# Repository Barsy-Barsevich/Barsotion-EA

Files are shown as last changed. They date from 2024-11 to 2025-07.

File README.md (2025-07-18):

# Barsotion GBK EpsilonAnomalain
Board computer for model rockets, the 10th board after Berkut

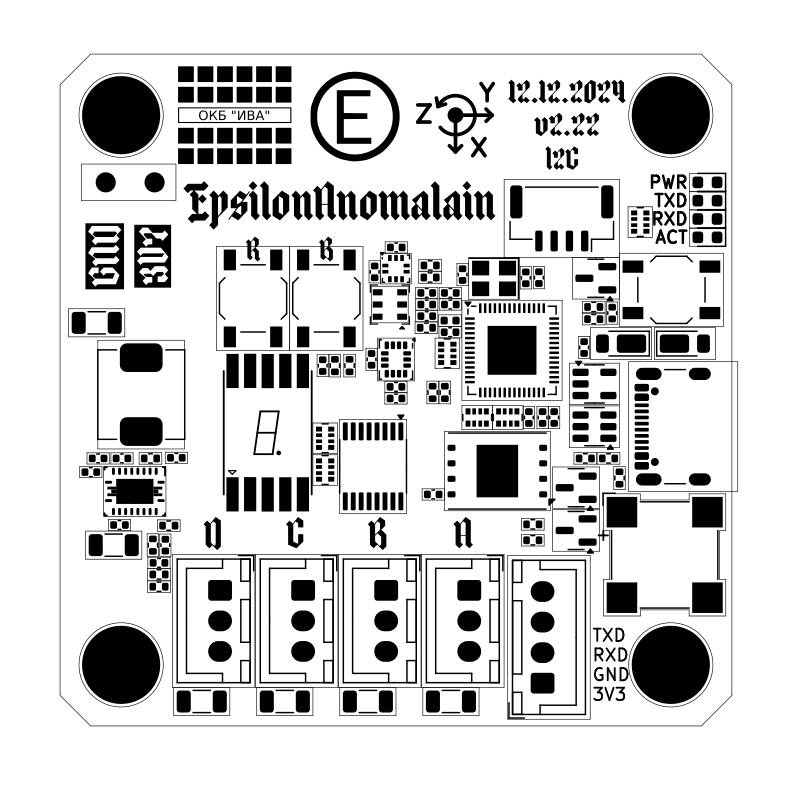
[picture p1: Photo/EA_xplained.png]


## ⚡️Manual
- [EA&TA_user_manual_revD.pdf (newest revision)](https://github.com/Barsy-Barsevich/Barsotion-TA/blob/main/Manual/EA%26TA_user_manual_revD.pdf)
- [EA&TA_user_manual_revC.pdf](https://github.com/Barsy-Barsevich/Barsotion-TA/blob/main/Manual/EA&TA_user_manual_revC.pdf)
- [EA&TA_user_manual_preliminary_edition_revB.pdf](https://github.com/Barsy-Barsevich/Barsotion-TA/blob/main/Manual/EA&TA_user_manual_preliminary_edition_revB.pdf)
- [EA&TA_user_manual_preliminary_edition_revA.pdf](https://github.com/Barsy-Barsevich/Barsotion-TA/blob/main/Manual/EA&TA_user_manual_preliminary_edition_revA.pdf)

## ⚡️Software
- [EA/TA software packet](https://github.com/Barsy-Barsevich/Barsotion-xA-software)

## ⚡️Continious progress
- [Previous version: Barsotion GBK DeltaAnomalain](https://github.com/Barsy-Barsevich/Barsotion-GBK-DeltaAnomalain)
- [Next version: Barsotion-TA (ThetaAnomalain)](https://github.com/Barsy-Barsevich/Barsotion-TA)

## ⚡️Schematic

## ⚡️Parameters
- Microcontroller: ESP32-S3FN8 (2x Xtensa LX7 core)
- Clock frequency: 240MHz
- Gyroscope: on-board ICM-42688-P (SPI, interrupt channel)
- Barometer: on-board, BMP388 (I2C)
- Hygrometer: on-board, AHT20 (I2C)
- Memory: 1Gbit SPI NAND Flash W25N04GVZEIG (Quad SPI)

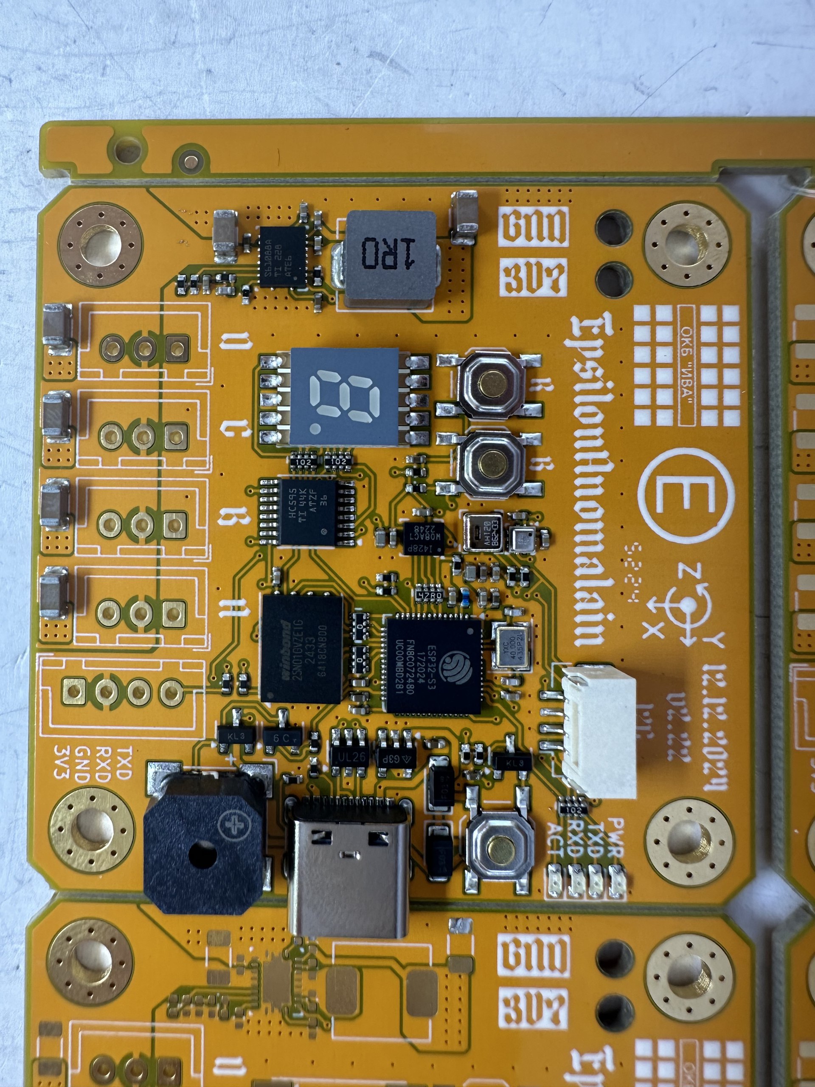
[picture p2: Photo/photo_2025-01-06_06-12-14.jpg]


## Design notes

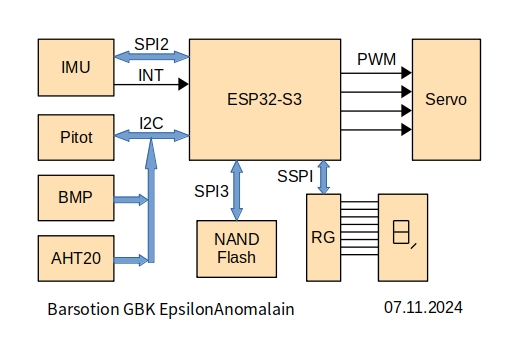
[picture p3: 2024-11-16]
Schematic/Barsotion_EA_BlockScheme1.jpg

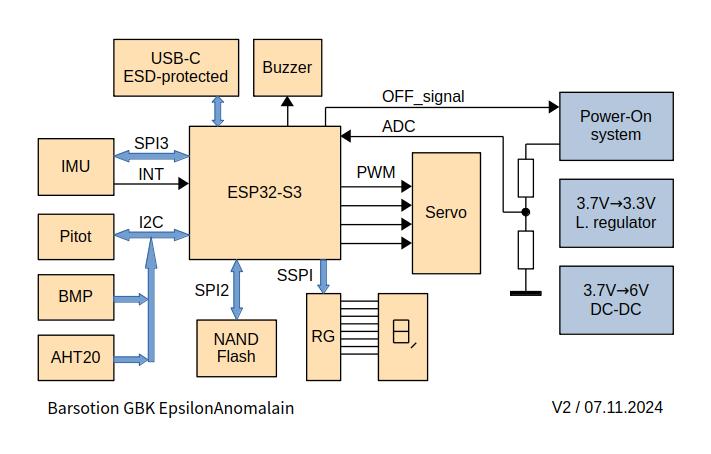
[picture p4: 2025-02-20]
Schematic/Barsotion_EA_BlockScheme2.jpg

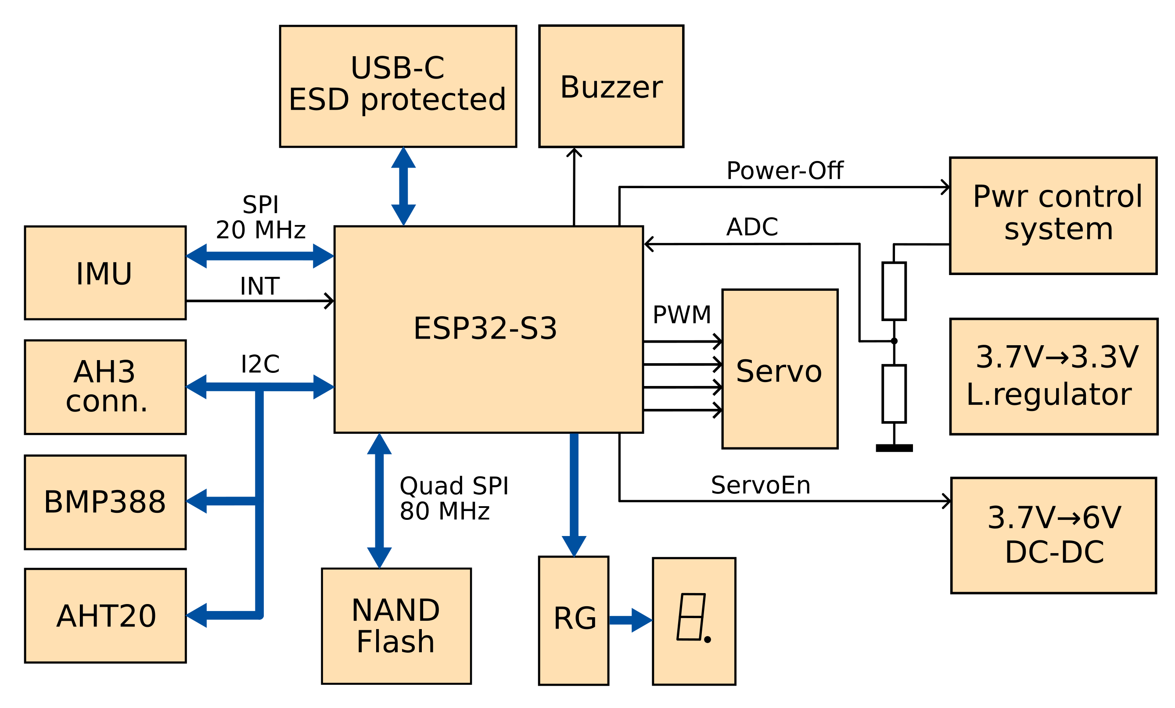
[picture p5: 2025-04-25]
Schematic/EA_Blockscheme.png

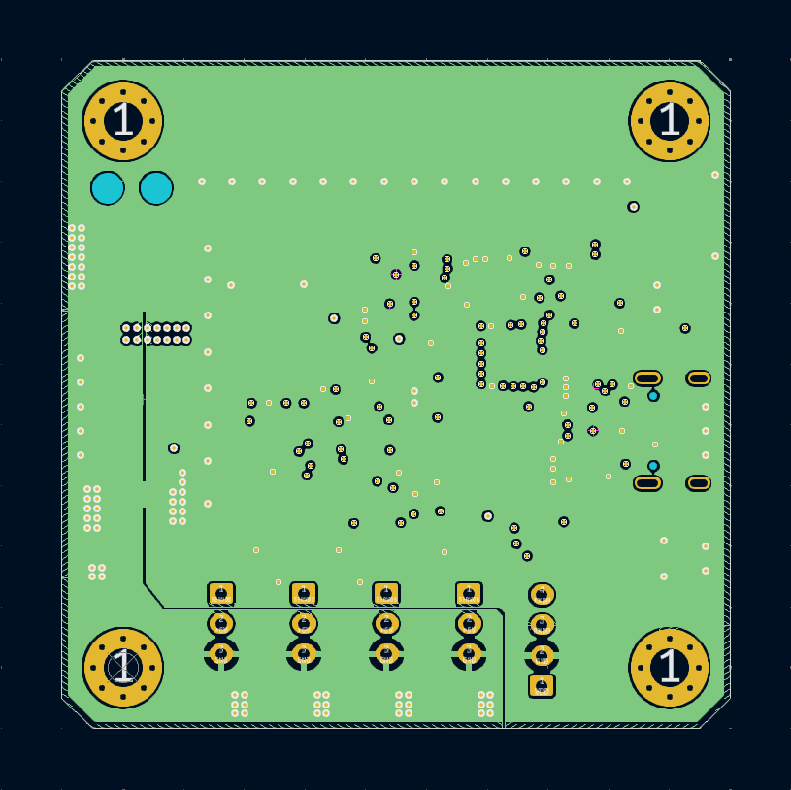
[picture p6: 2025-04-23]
Topology/EA Layer 2 - GND.png

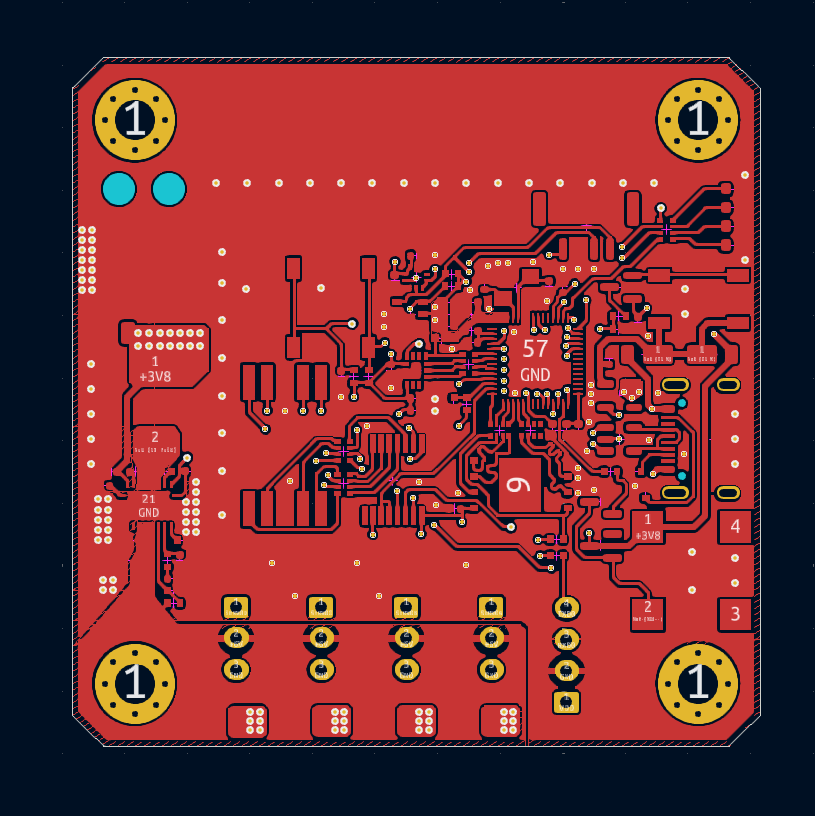
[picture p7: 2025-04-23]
Topology/EA Layer 1 - Top signal.png

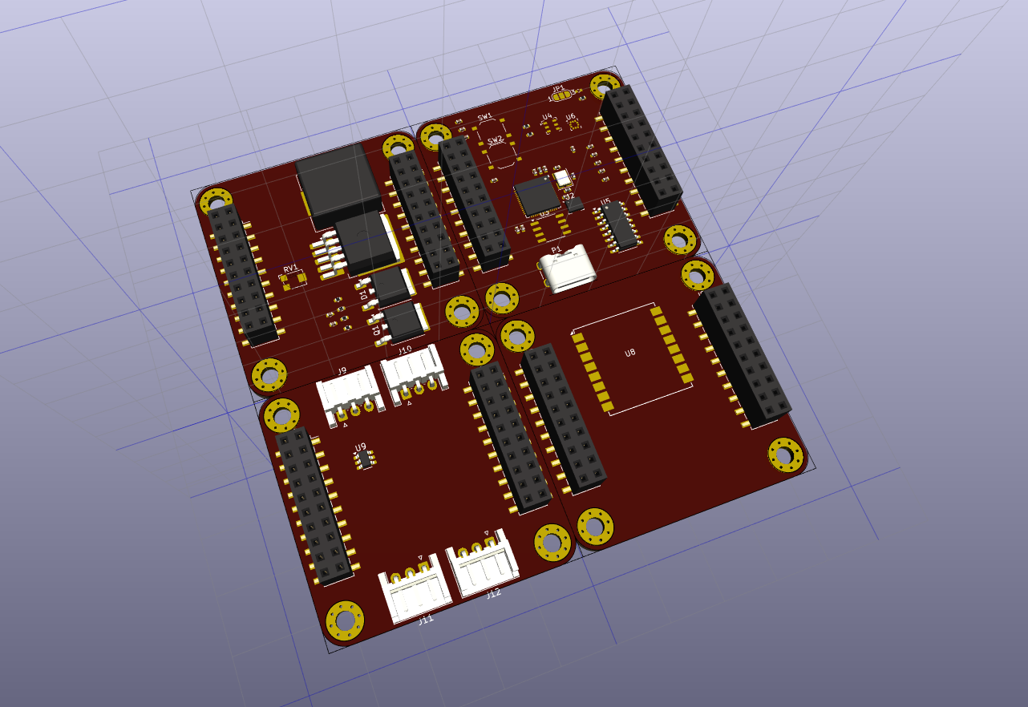
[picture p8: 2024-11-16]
Prev/EpsilonAnomalain/Screenshot at 2024-08-06 22-45-56.png

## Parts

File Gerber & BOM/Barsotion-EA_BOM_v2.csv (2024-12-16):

Reference | Value | Datasheet | Footprint | Qty | DNP | Description | Mfr.Part
BZ1 | CMT-8504-100 | https://www.lcsc.com/datasheet/lcsc_datasheet_2410010302_Murata-Electronics-PKLCS1212E2000-R1_C184513.pdf | Buzzer_Beeper:MagneticBuzzer_CUI_CMT-8504-100-SMT | 1 |  | Buzzer, polarized | CMT-8504-100
C1,C4,C5,C6,C8,C15,C17,C21,C25,C34 | 100nF | ~ | Capacitor_SMD:C_0402_1005Metric | 10 |  | Unpolarized capacitor
C2,C23 | 10uF | ~ | Capacitor_SMD:C_0402_1005Metric | 2 |  | Unpolarized capacitor
C3,C7,C10,C12,C16,C19,C32,C33 | 1uF | ~ | Capacitor_SMD:C_0402_1005Metric | 8 |  | Unpolarized capacitor
C9,C14,C26,C29,C30,C31 | 100uF | ~ | Capacitor_SMD:C_1206_3216Metric | 6 |  | Unpolarized capacitor
C11,C22,C24 | 10nF | ~ | Capacitor_SMD:C_0402_1005Metric | 3 |  | Unpolarized capacitor
C13 | 1nF | ~ | Capacitor_SMD:C_0402_1005Metric | 1 |  | Unpolarized capacitor
C18 | 43pF | ~ | Capacitor_SMD:C_0402_1005Metric | 1 |  | Unpolarized capacitor
C20 | 8.2nF | ~ | Capacitor_SMD:C_0402_1005Metric | 1 |  | Unpolarized capacitor
C27,C28 | 12pF | ~ | Capacitor_SMD:C_0402_1005Metric | 2 |  | Unpolarized capacitor
D1,D2 | DFLS130L | ~ | Diode_SMD:D_PowerDI-123 | 2 |  | Schottky diode
D3,D4 | BAT54C | http://www.diodes.com/_files/datasheets/ds11005.pdf | Package_TO_SOT_SMD:SOT-23 | 2 |  | dual schottky barrier diode, common cathode
D5 | Power | ~ | LED_SMD:LED_0603_1608Metric | 1 |  | Yellow Light emitting diode
D6 | TX0 | ~ | LED_SMD:LED_0603_1608Metric | 1 |  | Yellow Light emitting diode
D7 | RX0 | ~ | LED_SMD:LED_0603_1608Metric | 1 |  | Yellow Light emitting diode
D8 | Action | ~ | LED_SMD:LED_0603_1608Metric | 1 |  | Yellow Light emitting diode
J1 | USB_C | https://www.usb.org/sites/default/files/documents/usb_type-c.zip | Connector_USB:USB_C_Receptacle_GCT_USB4105-xx-A_16P_TopMnt_Horizontal | 1 |  | USB 2.0-only 16P Type-C Receptacle connector, mfr part TYPE C-DB-116PWB | TYPE C-DB-116PWB
J2 | I2C | ~ | Connector_JST:JST_GH_SM04B-GHS-TB_1x04-1MP_P1.25mm_Horizontal | 1 |  | Generic connector, single row, 01x04, script generated | A1257WR-S-4P
L1 | 2.2nH | https://www.lcsc.com/datasheet/lcsc_datasheet_2409302232_APV-APH0630T1R0M_C5349700.pdf | Inductor_SMD:L_0402_1005Metric | 1 |  | Inductor
L2 | 1uH | https://www.lcsc.com/datasheet/lcsc_datasheet_2409302232_APV-APH0630T1R0M_C5349700.pdf | Inductor_SMD:L_APV_APH0630 | 1 |  | Power inductor | APH0630T1R0M
Q1 | BC817-40 | https://www.onsemi.com/pub/Collateral/BC818-D.pdf | Package_TO_SOT_SMD:SOT-23 | 1 |  | 0.8A Ic, 45V Vce, NPN Transistor, SOT-23
R1 | 470k | ~ | Resistor_SMD:R_0402_1005Metric | 1 |  | Resistor
R2 | 267k | ~ | Resistor_SMD:R_0402_1005Metric | 1 |  | Resistor
R3 | 118k | ~ | Resistor_SMD:R_0402_1005Metric | 1 |  | Resistor
R4 | 100 | ~ | Resistor_SMD:R_0402_1005Metric | 1 |  | Resistor
R5 | 28.7k | ~ | Resistor_SMD:R_0402_1005Metric | 1 |  | Resistor
R6,R10,R15,R16,R17 | 10k | ~ | Resistor_SMD:R_0402_1005Metric | 5 |  | Resistor
R7 | 124k | ~ | Resistor_SMD:R_0402_1005Metric | 1 |  | Resistor
R8,R9,R11,R12,R18,R19 | 5.1k | ~ | Resistor_SMD:R_0402_1005Metric | 6 |  | Resistor
R13,R14 | 470 | ~ | Resistor_SMD:R_0402_1005Metric | 2 |  | Resistor
RN1 | 47 | ~ | Resistor_SMD:R_Array_Convex_4x0402 | 1 |  | 4 resistor network, parallel topology, split
RN2,RN4,RN5 | 1k | ~ | Resistor_SMD:R_Array_Convex_4x0402 | 3 |  | 4 resistor network, parallel topology
RN3,RN6 | 0 | ~ | Resistor_SMD:R_Array_Convex_4x0402 | 2 |  | 4 resistor network, parallel topology
SW1,SW2,SW3 | TS-1187A-B-A-B | ~ | Button_Switch_SMD:SW_SPST_TL3342 | 3 |  | TS-1187A-B-A-B | TS-1187A-B-A-B
U1 | AP2112K-3.3 | https://www.diodes.com/assets/Datasheets/AP2112.pdf | Package_TO_SOT_SMD:SOT-23-5 | 1 |  | 600mA low dropout linear regulator, with enable pin, 3.8V-6V input voltage range, 3.3V fixed positive output, SOT-23-5 | AP2112K-3.3
U2 | TPS61088 |  | UltraLibrarian:RHL0020A | 1 |  | Texas Instruments DC-DC Pullup converter | TPS61088
U3 | USBLC6-2SC6 | https://www.st.com/resource/en/datasheet/usblc6-2.pdf | Package_TO_SOT_SMD:SOT-23-6 | 1 |  | Very low capacitance ESD protection diode, 2 data-line, SOT-23-6 | USBLC6-2SC6
U4 | ESP32-S3FN8 | https://www.espressif.com/sites/default/files/documentation/esp32-s3_datasheet_en.pdf | Package_DFN_QFN:QFN-56-1EP_7x7mm_P0.4mm_EP4x4mm | 1 |  | Microcontroller, Wi-Fi 802.11b/g/n, Bluetooth, 32bit | ESP32-S3FN8
U5 | ICM-42688-P | https://invensense.tdk.com/wp-content/uploads/2020/04/ds-000347_icm-42688-p-datasheet.pdf | Package_LGA:LGA-14_3x2.5mm_P0.5mm_LayoutBorder3x4y | 1 |  | InvenSense High-precision 6-axes gyroscope accelerometer | ICM-42688-P
U6 | AHT20 | https://files.seeedstudio.com/wiki/Grove-AHT20_I2C_Industrial_Grade_Temperature_and_Humidity_Sensor/AHT20-datasheet-2020-4-16.pdf | CustomPackage:AHT20 | 1 |  | Digital hygrometer | AHT20
U7 | BMP388 | https://pdf1.alldatasheet.com/datasheet-pdf/download/1132070/BOSCH/BMP388.html | CustomPackage:BMP388 | 1 |  | Bosch barometer thermometer | BMP388
U8 | SS206SURWA/S530-A3/S290 | https://www.lcsc.com/datasheet/lcsc_datasheet_2409302134_Everlight-Elec-SS206SURWA-S530-A3-S290_C19188062.pdf | CustomPackage:SS206SURWA | 1 |  | One digit 7 segment hyper red LED, common anode | SS206SURWA/S530-A3/S290
U9 | 74HC595 | http://www.ti.com/lit/ds/symlink/sn74hc595.pdf | Package_SO:TSSOP-16_4.4x5mm_P0.65mm | 1 |  | 8-bit serial in/out Shift Register 3-State Outputs
U10 | W25N01GVZEIG | https://www.lcsc.com/datasheet/lcsc_datasheet_2304140030_Winbond-Elec-W25N01GVZEIG_C907680.pdf | Package_SON:WSON-8-1EP_8x6mm_P1.27mm_EP3.4x4.3mm | 1 |  | SPI NAND Flash 1Gbit chip | W25N01GVZEIG
Y1 | 40 MHz | ~ | Crystal:Crystal_SMD_3225-4Pin_3.2x2.5mm | 1 |  | Four pin crystal, GND on pins 2 and 4

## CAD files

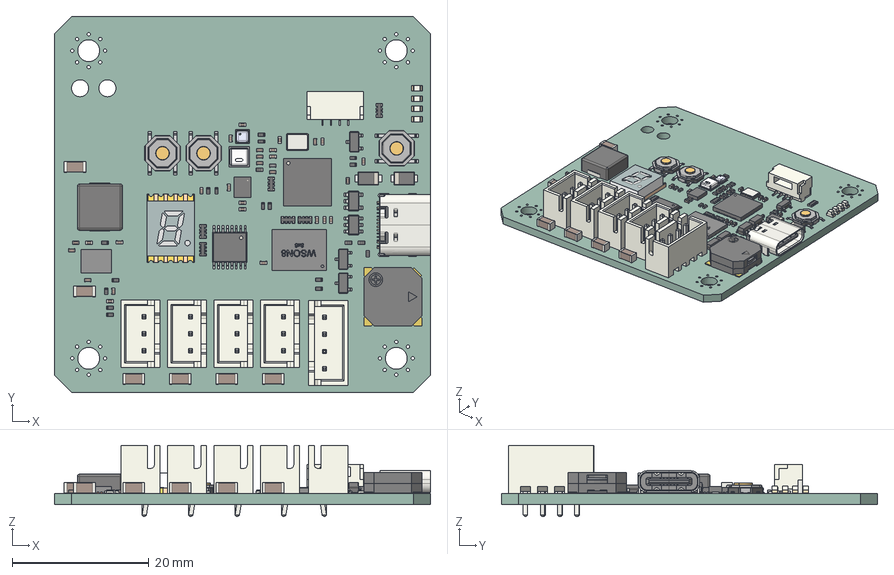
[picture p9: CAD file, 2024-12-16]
Step/Barsotion-EA_STEP_v2.22.step
55.0 x 55.0 x 10.4 mm
R_Array_Convex_4x0402 x 6
LED_0603_1608Metric x 4
C_0402_1005Metric x 28
CQ assembly
D_PowerDI_123 x 2
JST_B3B_XH_A x 4
R_0402_1005Metric x 19
L_APV_APH0630
C_1206_3216Metric x 6
SOT_23_5
SOT_23_6
SW_SPST_TL3342 x 3
BMP388
JST_B4B_XH_A
AHT20 Sensor v0
RHL0020A_ASM
SOT_23 x 3
CMT-8503-87_90
WSON8-8x6
JST_SM04B_GHS_TB
L_0402_1005Metric
LGA_14_3x25mm_P05mm_LayoutBorder3x4y
ACSC02-41SURKWA-F01
Crystal_SMD_3225-4Pin_3.2x2.5mm
USB_C_Receptacle_16P_TopMnt_Horizontal_GCT_USB4105-xx-A
TSSOP_16_44x5mm_P065mm
EpsilonAnomalain_PCB

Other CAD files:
Step/Barsotion-EA_STEP_v2.17.step

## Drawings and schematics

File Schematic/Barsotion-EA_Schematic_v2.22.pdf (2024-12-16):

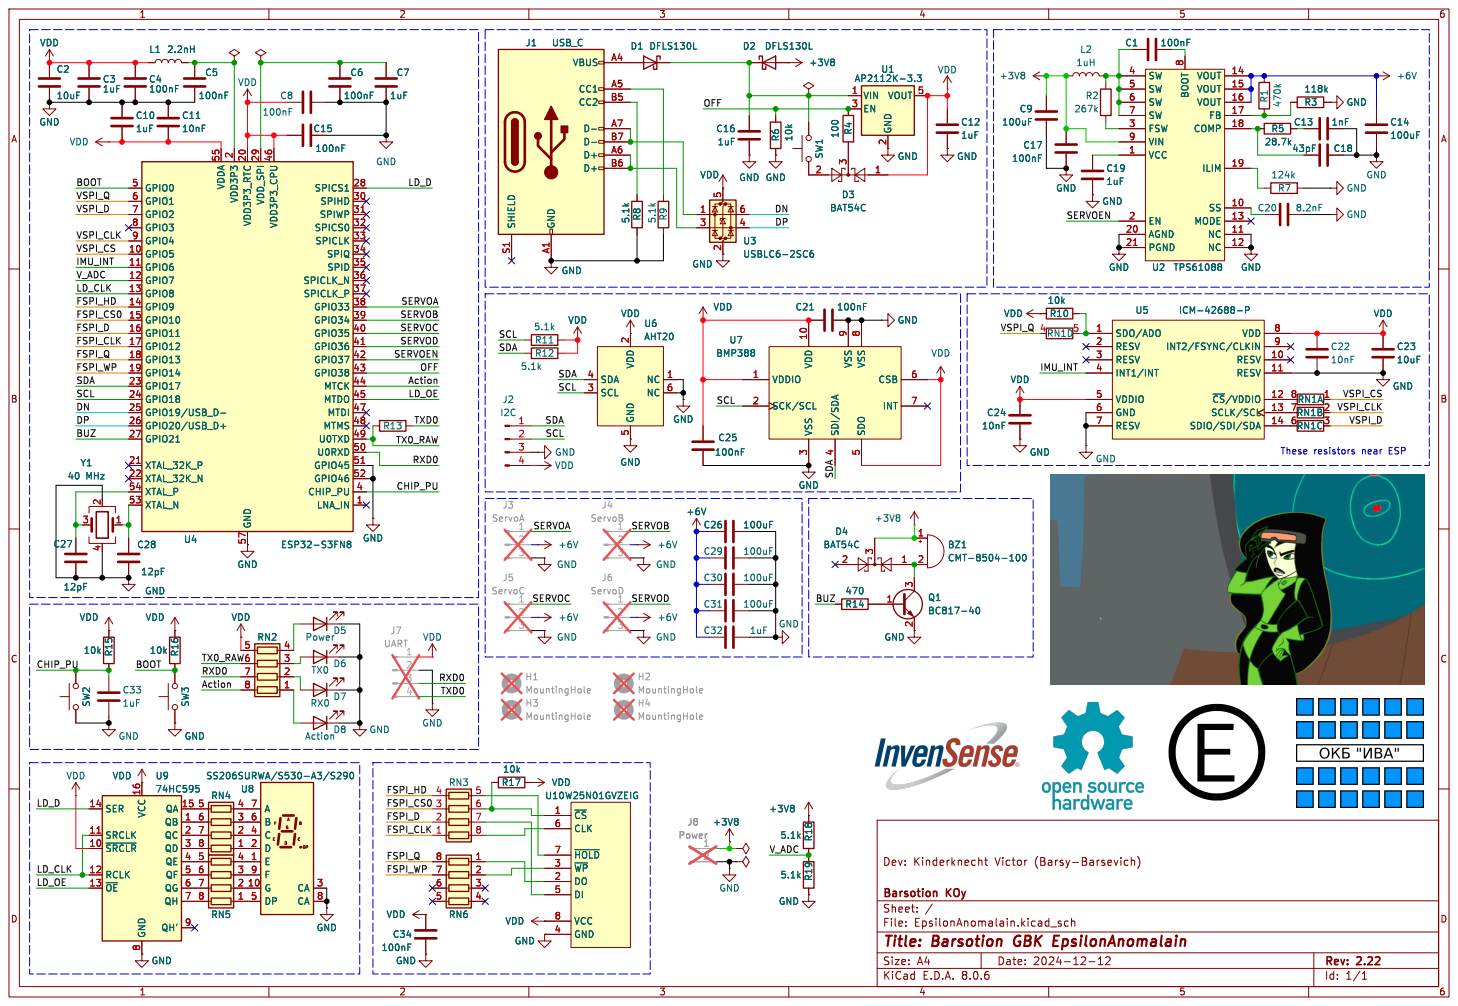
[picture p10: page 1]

2 VDD3P3_RTC 20 XTAL_32K_P 21 XTAL_32K_N 22 GPIO17 23 GPIO18 24 GPIO19/USB_D- 25 GPIO20/USB_D+ 26 GPIO21 27 SPICS1 28 VDD_SPI 29 SPIHD 30 SPIWP 31 SPICS0 32 SPICLK 33 SPIQ 34 SPID 35 SPICLK_P 37 GPIO33 38 GPIO34 39 CHIP_PU 4 GPIO35 40 GPIO36 41 GPIO37 42 GPIO38 43 MTCK 44 VDD3P3_CPU 46 MTDI 47 MTMS 48 U0TXD 49 GPIO0 5 U0RXD 50 GPIO46 52 XTAL_N 53 XTAL_P 54 VDDA 55 GND 57 GPIO1 6 GPIO2 7 GPIO3 8 GPIO4 9 U4 ESP32-S3FN8 GND

2 VDD3P3_RTC 20 XTAL_32K_P 21 XTAL_32K_N 22 GPIO17 23 GPIO18 24 GPIO19/USB_D- 25 GPIO20/USB_D+ 26 GPIO21 27 SPICS1 28 VDD_SPI 29 SPIHD 30 SPIWP 31 SPICS0 32 SPICLK 33 SPIQ 34 SPID 35 SPICLK_P 37 GPIO33 38 GPIO34 39 CHIP_PU 4 GPIO35 40 GPIO36 41 GPIO37 42 GPIO38 43 MTCK 44 VDD3P3_CPU 46 MTDI 47 MTMS 48 U0TXD 49 GPIO0 5 U0RXD 50 GPIO46 52 XTAL_N 53 XTAL_P 54 VDDA 55 GND 57 GPIO1 6 GPIO2 7 GPIO3 8 GPIO4 9 GND

8 QH' 9 VDD GND GND

Id: 1/1 Title: Barsotion GBK EpsilonAnomalain

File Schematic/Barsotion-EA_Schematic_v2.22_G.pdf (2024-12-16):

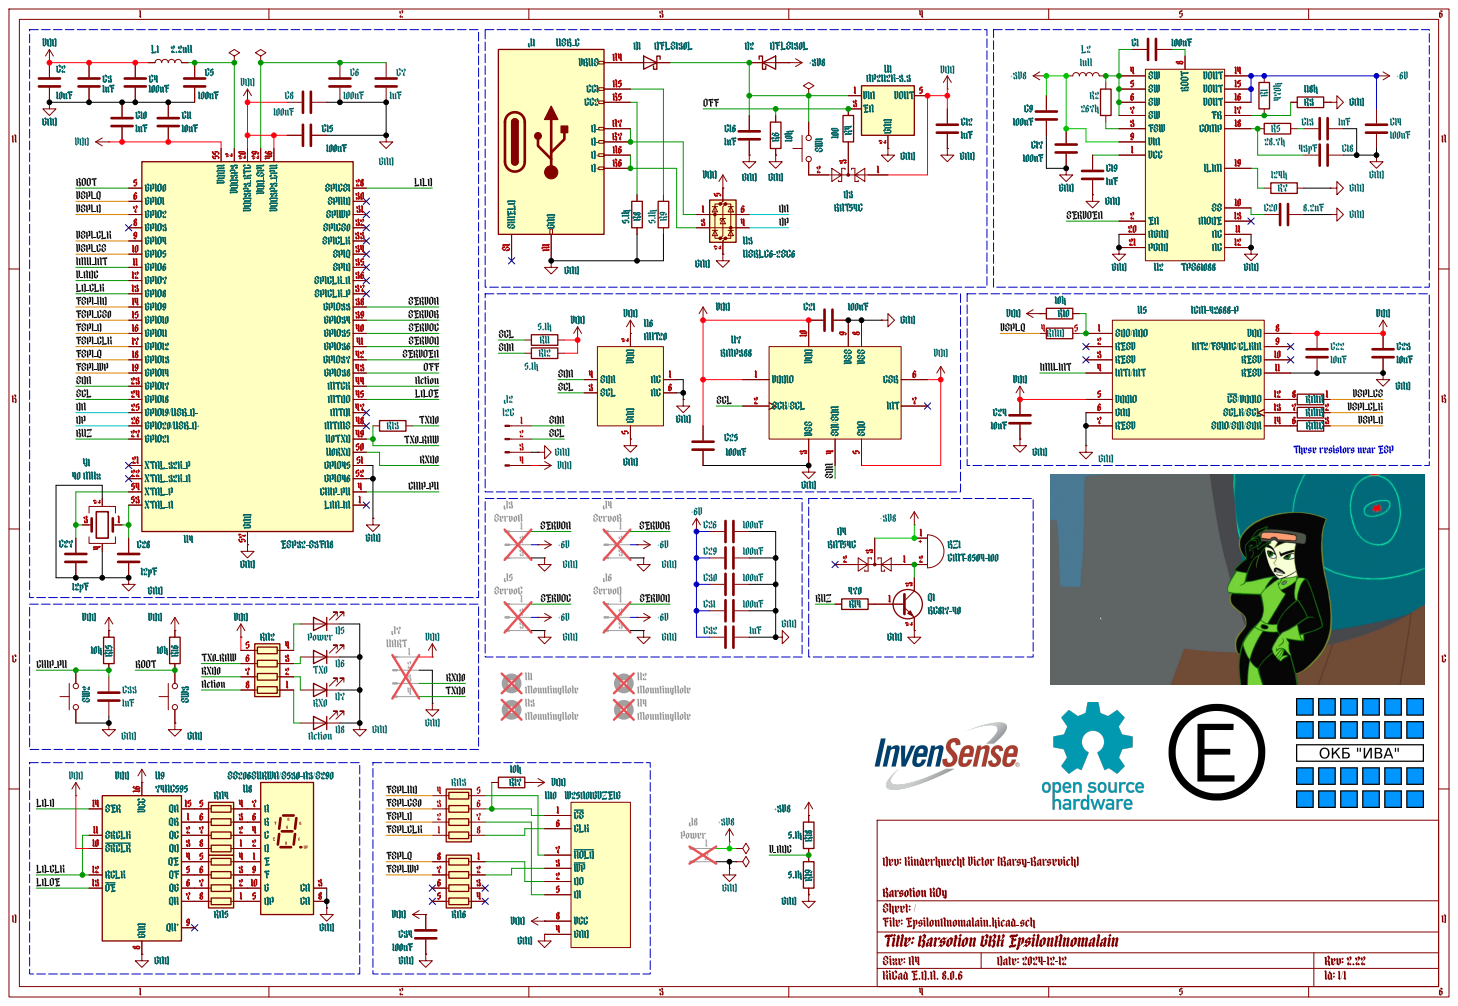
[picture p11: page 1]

2 EN 3 VOUT5 U1 AP2112K-3.3 GND GND R4 100 SW1 GND

8 VIN 9 GND GND GND

2 VDD3P3_RTC20 XTAL_32K_P 21 XTAL_32K_N 22 GPIO17 23 GPIO18 24 GPIO19/USB_D- 25 GPIO20/USB_D+ 26 GPIO21 27 SPICS128 VDD_SPI29 SPIHD30 SPIWP31 SPICS032 SPICLK33 SPIQ34 SPID35 SPICLK_P37 GPIO3338 GPIO3439 CHIP_PU4 GPIO3540 GPIO3641 GPIO3742 GPIO3843 MTCK 44 VDD3P3_CPU46 MTDI 47 MTMS 48 U0TXD49 GPIO0 5 U0RXD50 GPIO4652 XTAL_N 53 XTAL_P 54 VDDA55 GND 57 GPIO1 6 GPIO2 7 GPIO3 8 GPIO4 9 U4 ESP32-S3FN8 C10

2 VDD3P3_RTC20 XTAL_32K_P 21 XTAL_32K_N 22 GPIO17 23 GPIO18 24 GPIO19/USB_D- 25 GPIO20/USB_D+ 26 GPIO21 27 SPICS128 VDD_SPI29 SPIHD30 SPIWP31 SPICS032 SPICLK33 SPIQ34 SPID35 SPICLK_P37 GPIO3338 GPIO3439 CHIP_PU4 GPIO3540 GPIO3641 GPIO3742 GPIO3843 MTCK 44 VDD3P3_CPU46 MTDI 47 MTMS 48 U0TXD49 GPIO0 5 U0RXD50 GPIO4652 XTAL_N 53 XTAL_P 54 VDDA55 GND 57 GPIO1 6 GPIO2 7 GPIO3 8 GPIO4 9C10

Theseresistors near ESP GND

File: EpsilonAnomalain.kicad_sch Sheet:/ BarsotionKOy Dev:KinderknechtVictor (Barsy-Barsevich) 1

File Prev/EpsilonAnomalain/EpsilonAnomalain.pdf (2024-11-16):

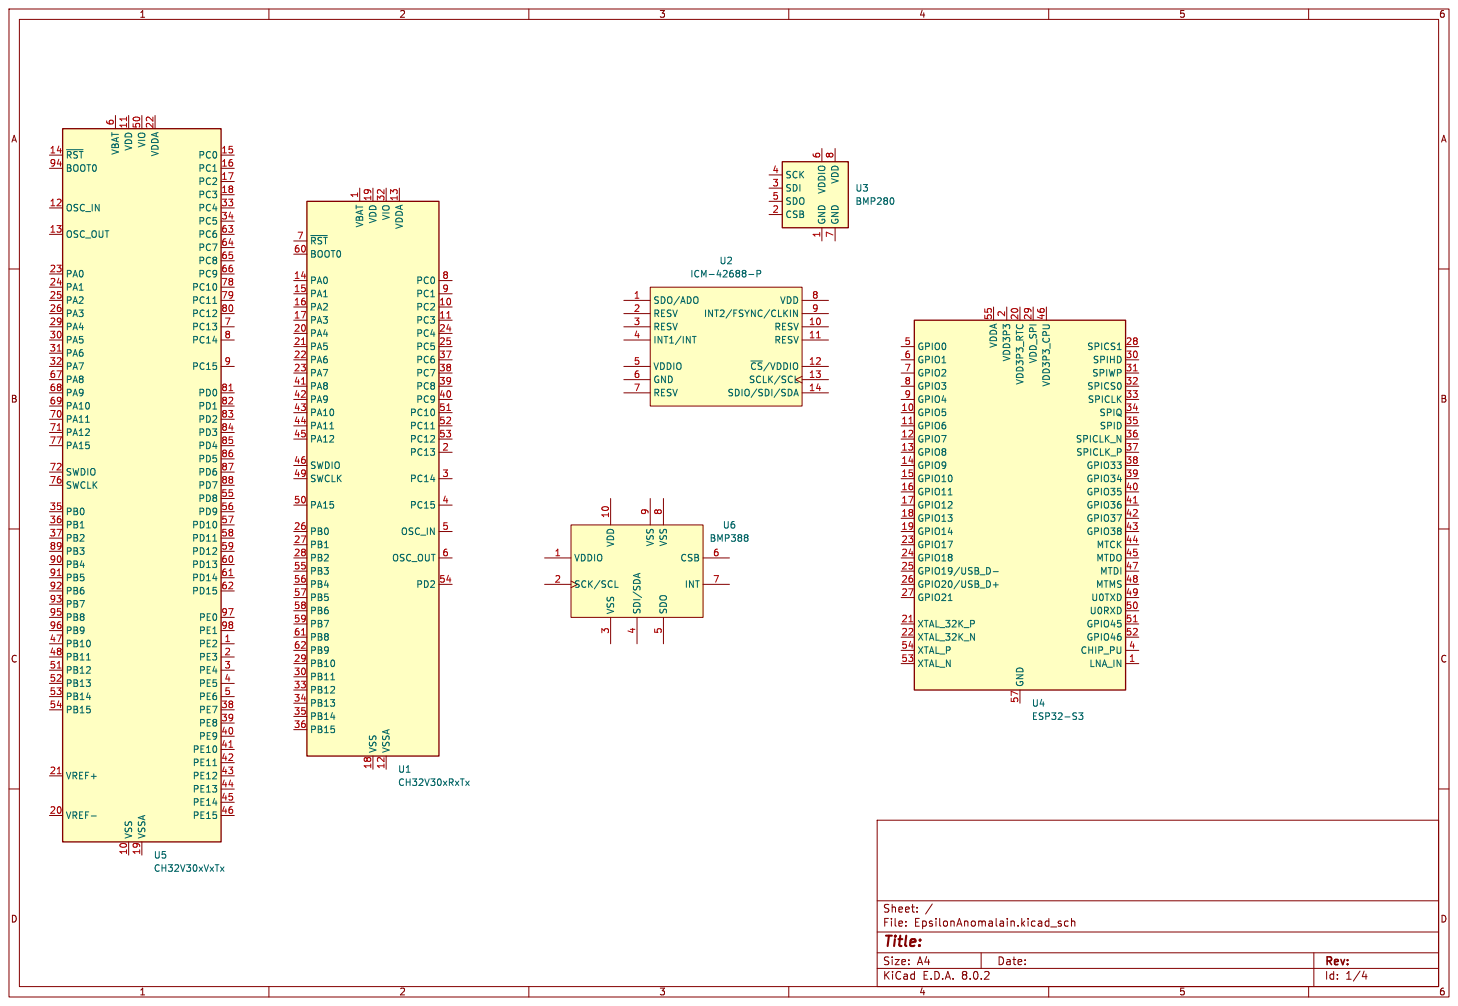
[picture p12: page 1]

Id: 1/4 Title: File: EpsilonAnomalain.kicad_sch Sheet: / Power1

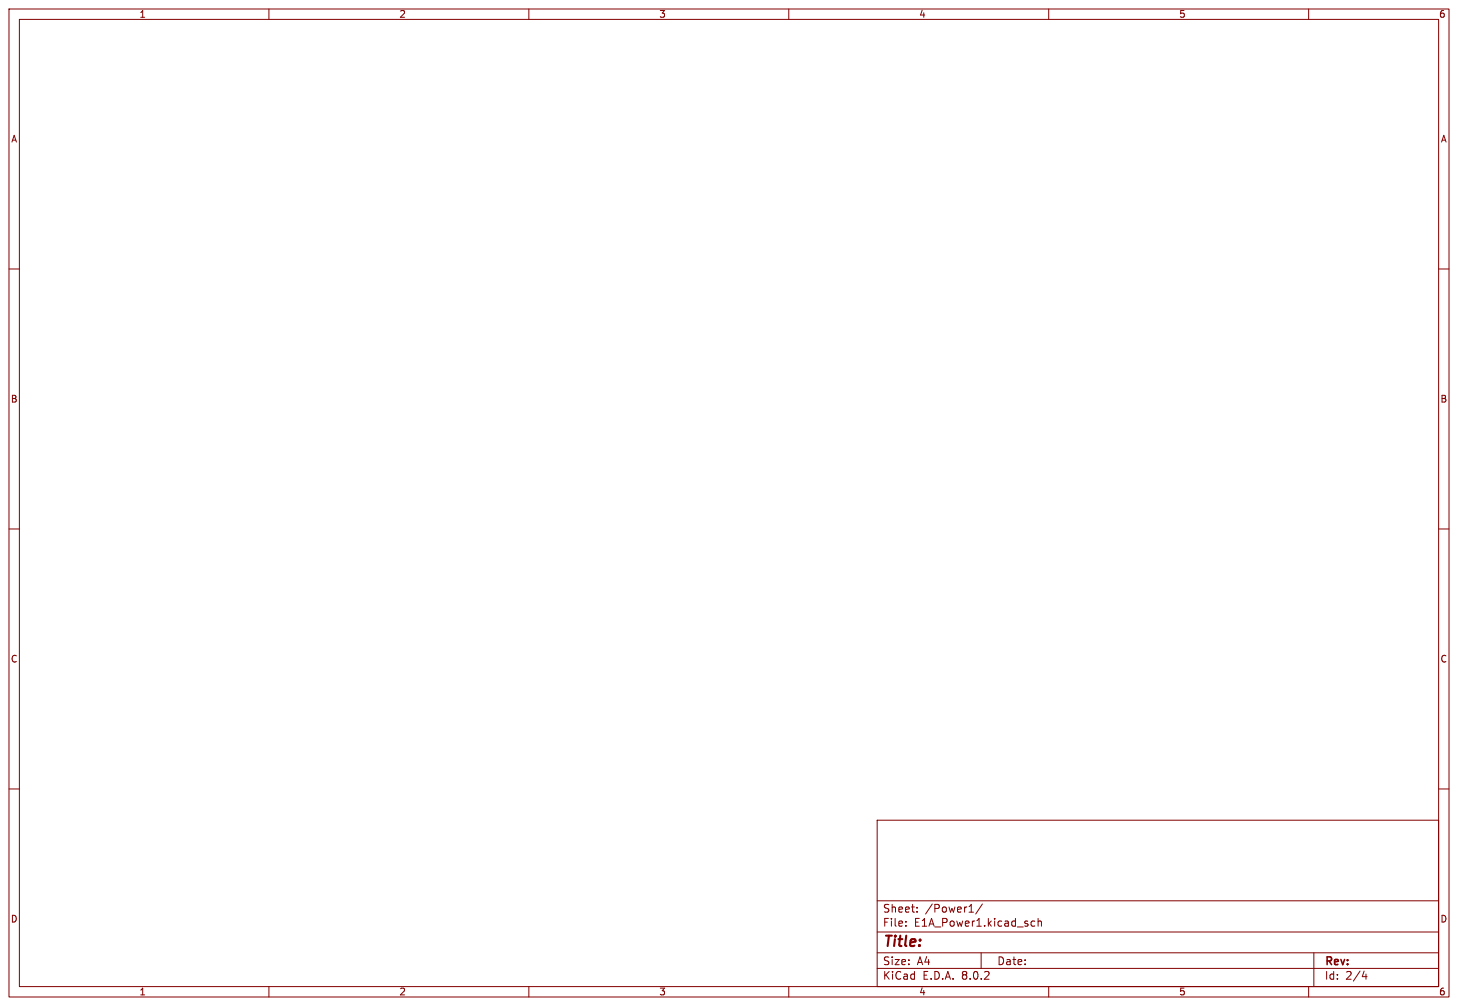
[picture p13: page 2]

Id: 2/4 Title: File: E1A_Power1.kicad_sch Sheet: /Power1/

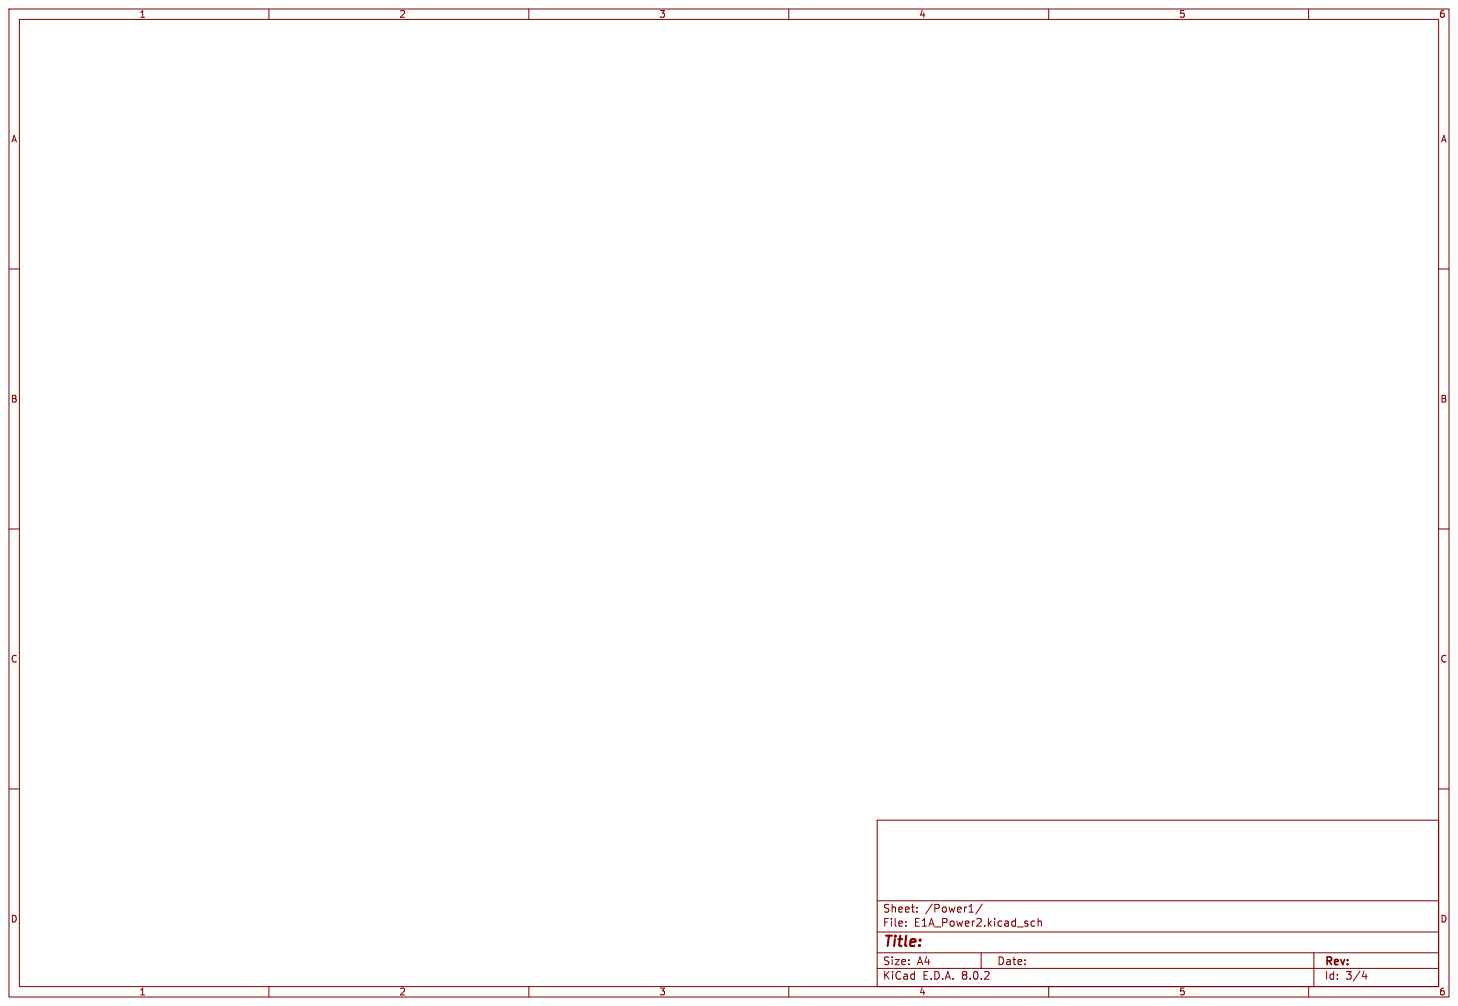
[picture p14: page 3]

Id: 3/4 Title: File: E1A_Power2.kicad_sch Sheet: /Power1/

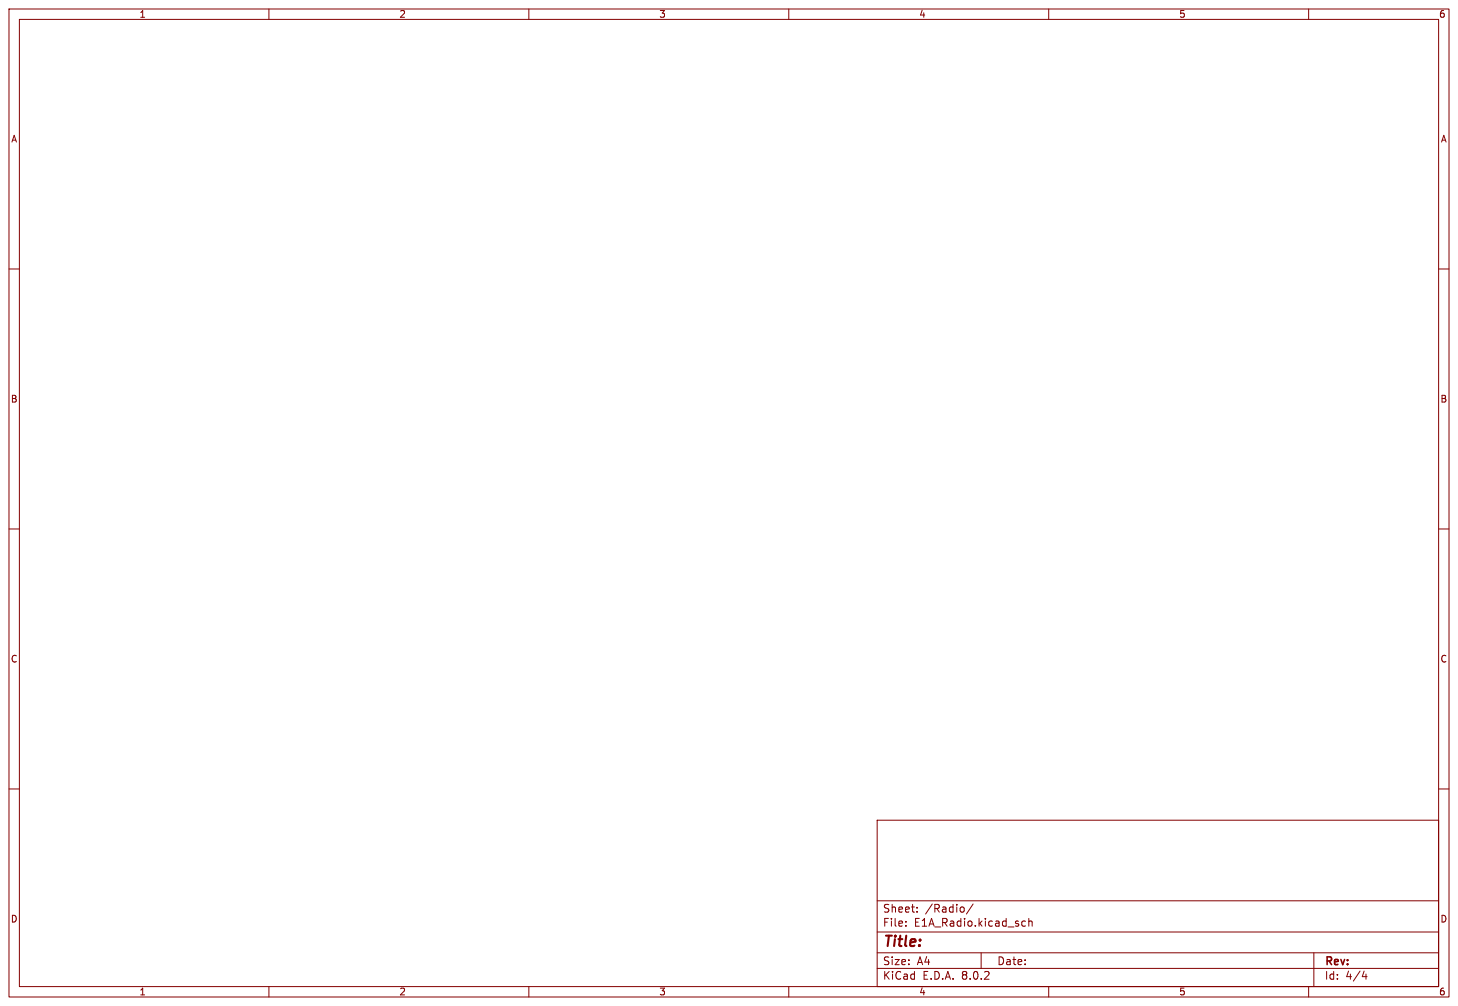
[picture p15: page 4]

Id: 4/4 Title: File: E1A_Radio.kicad_sch Sheet: /Radio/

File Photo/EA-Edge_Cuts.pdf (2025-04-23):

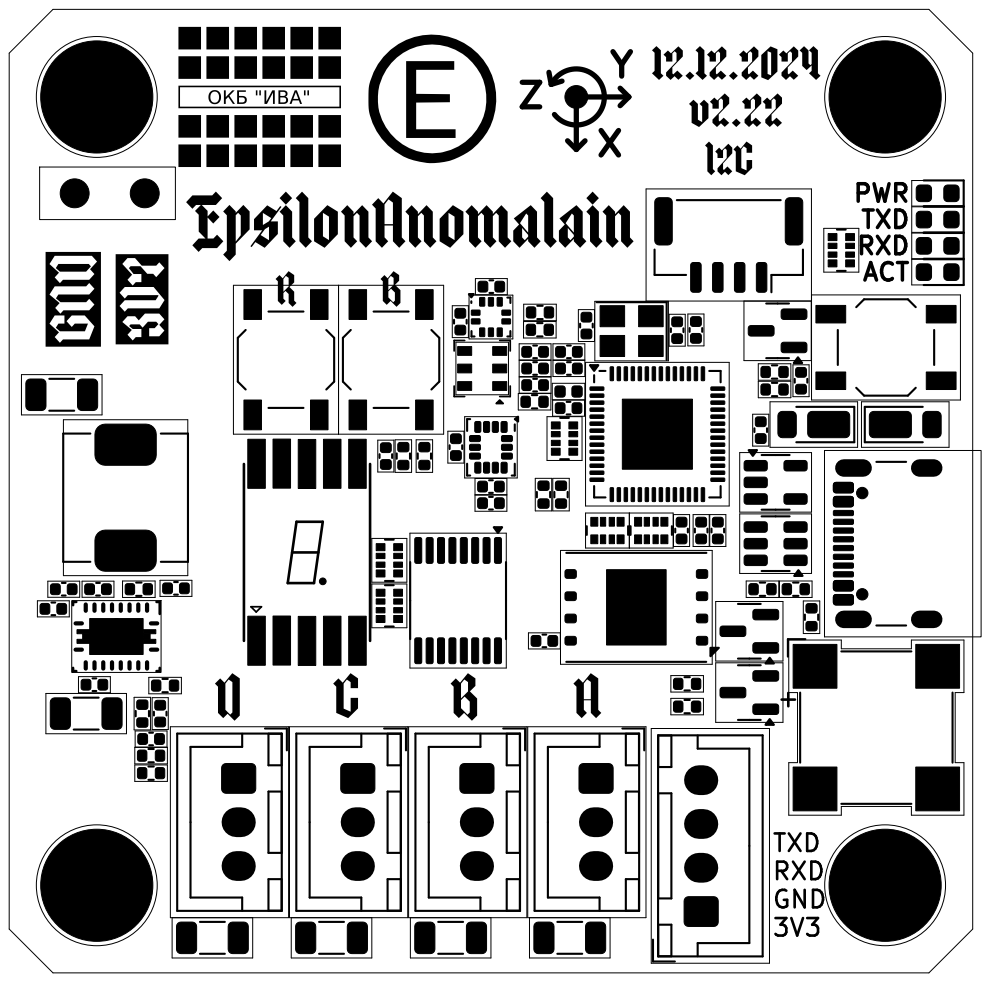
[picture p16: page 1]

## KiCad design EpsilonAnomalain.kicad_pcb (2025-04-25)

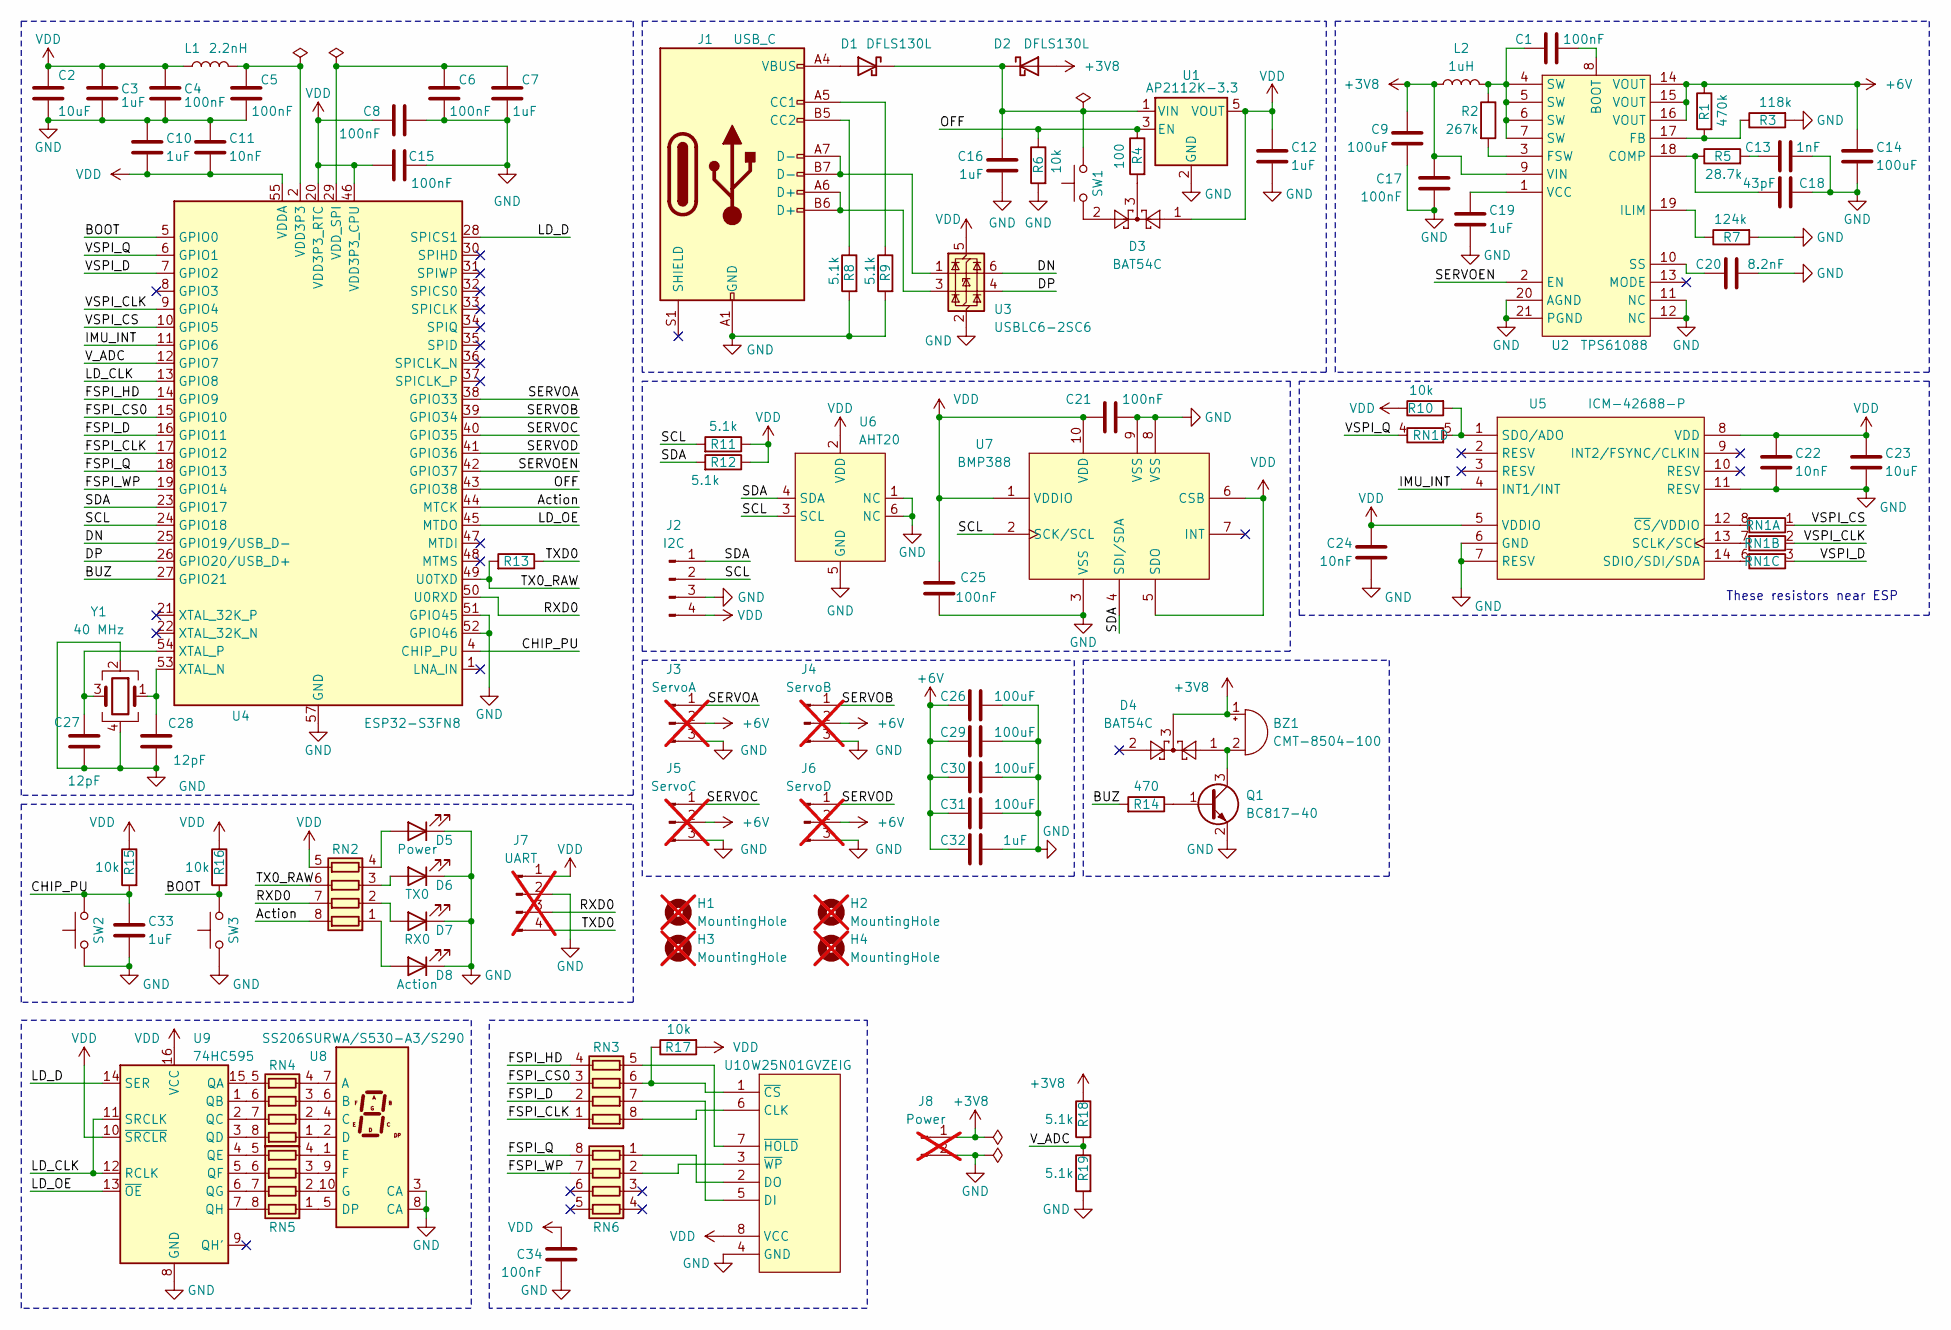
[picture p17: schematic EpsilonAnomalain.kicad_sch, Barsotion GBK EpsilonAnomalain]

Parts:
BZ1: CMT-8504-100; MagneticBuzzer_CUI_CMT-8504-100-SMT; Mfr.Part CMT-8504-100
C1, C4, C5, C6, C8, C15, C17, C21, C25, C34: 100nF; C_0402_1005Metric
C2, C23: 10uF; C_0402_1005Metric
C3, C7, C10, C12, C16, C19, C32, C33: 1uF; C_0402_1005Metric
C9, C14, C26, C29, C30, C31: 100uF; C_1206_3216Metric
C11, C22, C24: 10nF; C_0402_1005Metric
C13: 1nF; C_0402_1005Metric
C18: 43pF; C_0402_1005Metric
C20: 8.2nF; C_0402_1005Metric
C27, C28: 12pF; C_0402_1005Metric
D1, D2: DFLS130L; D_PowerDI-123
D3, D4: BAT54C; SOT-23
D5: Power; LED_0603_1608Metric
D6: TX0; LED_0603_1608Metric
D7: RX0; LED_0603_1608Metric
D8: Action; LED_0603_1608Metric
H1, H2, H3, H4: MountingHole; MountingHole_3.2mm_M3_Pad_Via; not fitted
J1: USB_C; USB_C_Receptacle_GCT_USB4105-xx-A_16P_TopMnt_Horizontal; Mfr.Part TYPE C-DB-116PWB
J2: I2C; JST_GH_SM04B-GHS-TB_1x04-1MP_P1.25mm_Horizontal; Mfr.Part A1257WR-S-4P
J3: ServoA; JST_XH_B3B-XH-A_1x03_P2.50mm_Vertical; not fitted
J4: ServoB; JST_XH_B3B-XH-A_1x03_P2.50mm_Vertical; not fitted
J5: ServoC; JST_XH_B3B-XH-A_1x03_P2.50mm_Vertical; not fitted
J6: ServoD; JST_XH_B3B-XH-A_1x03_P2.50mm_Vertical; not fitted
J7: UART; JST_XH_B4B-XH-A_1x04_P2.50mm_Vertical; not fitted
J8: Power; Battery_3V7_Cable_connector_v2; not fitted
L1: 2.2nH; L_0402_1005Metric
L2: 1uH; L_APV_APH0630; Mfr.Part APH0630T1R0M
Q1: BC817-40; SOT-23
R1: 470k; R_0402_1005Metric
R2: 267k; R_0402_1005Metric
R3: 118k; R_0402_1005Metric
R4: 100; R_0402_1005Metric
R5: 28.7k; R_0402_1005Metric
R6, R10, R15, R16, R17: 10k; R_0402_1005Metric
R7: 124k; R_0402_1005Metric
R8, R9, R11, R12, R18, R19: 5.1k; R_0402_1005Metric
R13, R14: 470; R_0402_1005Metric
RN1: 47; R_Array_Convex_4x0402
RN2, RN4, RN5: 1k; R_Array_Convex_4x0402
RN3, RN6: 0; R_Array_Convex_4x0402
SW1, SW2, SW3: TS-1187A-B-A-B; SW_SPST_TL3342; Mfr.Part TS-1187A-B-A-B
U1: AP2112K-3.3; SOT-23-5; Mfr.Part AP2112K-3.3
U2: TPS61088; RHL0020A; Mfr.Part TPS61088
U3: USBLC6-2SC6; SOT-23-6; Mfr.Part USBLC6-2SC6
U4: ESP32-S3FN8; QFN-56-1EP_7x7mm_P0.4mm_EP4x4mm; Mfr.Part ESP32-S3FN8
U5: ICM-42688-P; LGA-14_3x2.5mm_P0.5mm_LayoutBorder3x4y; Mfr.Part ICM-42688-P
U6: AHT20; Mfr.Part AHT20
U7: BMP388; BMP388_v2; Mfr.Part BMP388
U8: SS206SURWA/S530-A3/S290; SS206SURWA; Mfr.Part SS206SURWA/S530-A3/S290
U9: 74HC595; TSSOP-16_4.4x5mm_P0.65mm
U10: W25N01GVZEIG; WSON-8-1EP_8x6mm_P1.27mm_EP3.4x4.3mm; Mfr.Part W25N01GVZEIG
Y1: 40 MHz; Crystal_SMD_3225-4Pin_3.2x2.5mm

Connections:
+3V8: BZ1.1 (+), C9.1, C17.1, D2.2 (A), D4.3, J8.1, L2.1, R18.1, U2.9 (VIN)
+6V: C14.1, C26.1, C29.1, C30.1, C31.1, C32.1, J3.2, J4.2, J5.2, J6.2, R1.1, U2.14 (VOUT), U2.15 (VOUT), U2.16 (VOUT)
/Action: RN2.8 (R1.2), U4.44 (MTCK)
/BOOT: R16.2, SW3.2, U4.5 (GPIO0)
/BUZ: R14.2, U4.27 (GPIO21)
/CHIP_PU: C33.1, R15.2, SW2.2, U4.4 (CHIP_PU)
/DN: U3.6 (I/O1), U4.25 (GPIO19/USB_D-)
/DP: U3.4 (I/O2), U4.26 (GPIO20/USB_D+)
/FSPI_CLK: RN3.1 (R1.1), U4.17 (GPIO12)
/FSPI_CS0: RN3.3 (R3.1), U4.15 (GPIO10)
/FSPI_D: RN3.2 (R2.1), U4.16 (GPIO11)
/FSPI_HD: RN3.4 (R4.1), U4.14 (GPIO9)
/FSPI_Q: RN6.8 (R1.2), U4.18 (GPIO13)
/FSPI_WP: RN6.7 (R2.2), U4.19 (GPIO14)
/IMU_INT: U4.11 (GPIO6), U5.4 (INT1/INT)
/LD_CLK: U4.13 (GPIO8), U9.11 (SRCLK), U9.12 (RCLK)
/LD_D: U4.28 (SPICS1), U9.14 (SER)
/LD_OE: U4.45 (MTDO), U9.13 (~OE)
/OFF: R4.1, R6.1, U1.3 (EN), U4.43 (GPIO38)
/RXD0: J7.3, RN2.7 (R2.2), U4.50 (U0RXD)
/SCL: J2.2, R11.2, U4.24 (GPIO18), U6.3 (SCL), U7.2 (SCK/SCL)
/SDA: J2.1, R12.2, U4.23 (GPIO17), U6.4 (SDA), U7.4 (SDI/SDA)
/SERVOA: J3.1, U4.38 (GPIO33)
/SERVOB: J4.1, U4.39 (GPIO34)
/SERVOC: J5.1, U4.40 (GPIO35)
/SERVOD: J6.1, U4.41 (GPIO36)
/SERVOEN: U2.2 (EN), U4.42 (GPIO37)
/TX0_RAW: R13.2, RN2.6 (R3.2), U4.49 (U0TXD)
/TXD0: J7.4, R13.1
/VSPI_CLK: RN1.2 (R2.1), U4.9 (GPIO4)
/VSPI_CS: RN1.1 (R1.1), U4.10 (GPIO5)
/VSPI_D: RN1.3 (R3.1), U4.7 (GPIO2)
/VSPI_Q: RN1.4 (R4.1), U4.6 (GPIO1)
/V_ADC: R18.2, R19.1, U4.12 (GPIO7)
GND: C2.2, C3.2, C4.2, C5.2, C6.2, C7.2, C8.2, C9.2, C10.1, C11.1, C12.2, C13.1, C14.2, C15.2, C16.2, C17.2, C18.1, C19.2, C20.1, C21.2, C22.2, C23.2, C24.2, C25.1, C26.2, C27.2, C28.2, C29.2, C30.2, C31.2, C32.2, C33.2, C34.2, D5.1 (K), D6.1 (K), D7.1 (K), D8.1 (K), J1.A1 (GND), J1.A12 (GND), J1.B1 (GND), J1.B12 (GND), J2.3, J3.3, J4.3, J5.3, J6.3, J7.2, J8.2, Q1.2 (E), R3.2, R6.2, R7.2, R8.2, R9.2, R19.2, SW2.1, SW3.1, U1.2 (GND), U2.11 (NC), U2.12 (NC), U2.20 (AGND), U2.21 (PGND), U3.2 (GND), U4.51 (GPIO45), U4.52 (GPIO46), U4.57 (GND), U5.6 (GND), U5.7 (RESV), U5.11 (RESV), U6.1 (NC), U6.5 (GND), U6.6 (NC), U7.3 (VSS), U7.8 (VSS), U7.9 (VSS), U8.3 (CA), U8.8 (CA), U9.8 (GND), U10.4 (GND), Y1.2, Y1.4
unnamed: BZ1.2 (-), D4.1, Q1.3 (C)
unnamed: C1.2, L2.2, R2.1, U2.4 (SW), U2.5 (SW), U2.6 (SW), U2.7 (SW)
unnamed: C5.1, L1.2, U4.2 (VDD3P3), U4.3 (VDD3P3)
unnamed: C13.2, R5.2
unnamed: D1.2 (A), J1.A4 (VBUS), J1.A9 (VBUS), J1.B4 (VBUS), J1.B9 (VBUS)
unnamed: C16.1, D1.1 (K), D2.1 (K), SW1.2, U1.1 (VIN)
unnamed: D3.2, SW1.1
unnamed: D3.3, R4.2
unnamed: D5.2 (A), RN2.4 (R4.1)
unnamed: D6.2 (A), RN2.3 (R3.1)
unnamed: D7.2 (A), RN2.2 (R2.1)
unnamed: D8.2 (A), RN2.1 (R1.1)
unnamed: J1.A5 (CC1), R9.1
unnamed: J1.B5 (CC2), R8.1
unnamed: J1.A6 (D+), J1.B6 (D+), U3.3 (I/O2)
unnamed: J1.A7 (D-), J1.B7 (D-), U3.1 (I/O1)
unnamed: Q1.1 (B), R14.1
unnamed: RN1.8 (R1.2), U5.12 (~CS/VDDIO)
unnamed: RN1.7 (R2.2), U5.13 (SCLK/SCL)
unnamed: RN1.6 (R3.2), U5.14 (SDIO/SDI/SDA)
unnamed: R10.2, RN1.5 (R4.2), U5.1 (SDO/ADO)
unnamed: RN3.8 (R1.2), U10.6 (CLK)
unnamed: RN3.7 (R2.2), U10.5 (DI)
unnamed: R17.1, RN3.6 (R3.2), U10.1 (~CS)
unnamed: RN3.5 (R4.2), U10.7 (~HOLD)
unnamed: RN4.1 (R1.1), U8.2 (D)
unnamed: RN4.8 (R1.2), U9.3 (QD)
unnamed: RN4.2 (R2.1), U8.4 (C)
unnamed: RN4.7 (R2.2), U9.2 (QC)
unnamed: RN4.3 (R3.1), U8.6 (B)
unnamed: RN4.6 (R3.2), U9.1 (QB)
unnamed: RN4.4 (R4.1), U8.7 (A)
unnamed: RN4.5 (R4.2), U9.15 (QA)
unnamed: RN5.1 (R1.1), U8.5 (DP)
unnamed: RN5.8 (R1.2), U9.7 (QH)
unnamed: RN5.2 (R2.1), U8.10 (G)
unnamed: RN5.7 (R2.2), U9.6 (QG)
unnamed: RN5.3 (R3.1), U8.9 (F)
unnamed: RN5.6 (R3.2), U9.5 (QF)
unnamed: RN5.4 (R4.1), U8.1 (E)
unnamed: RN5.5 (R4.2), U9.4 (QE)
unnamed: RN6.1 (R1.1), U10.2 (DO)
unnamed: RN6.2 (R2.1), U10.3 (~WP)
unnamed: C1.1, U2.8 (BOOT)
unnamed: C18.2, R5.1, U2.18 (COMP)
unnamed: R1.2, R3.1, U2.17 (FB)
unnamed: R2.2, U2.3 (FSW)
unnamed: R7.1, U2.19 (ILIM)
unnamed: C20.2, U2.10 (SS)
unnamed: C19.1, U2.1 (VCC)
unnamed: C6.1, C7.1, U4.29 (VDD_SPI)
unnamed: C28.1, U4.53 (XTAL_N), Y1.1
unnamed: C27.1, U4.54 (XTAL_P), Y1.3
VDD: C2.1, C3.1, C4.1, C8.1, C10.2, C11.2, C12.1, C15.1, C21.1, C22.1, C23.1, C24.1, C25.2, C34.1, D3.1, J2.4, J7.1, L1.1, R10.1, R11.1, R12.1, R15.1, R16.1, R17.2, RN2.5 (R4.2), U1.5 (VOUT), U3.5 (VBUS), U4.20 (VDD3P3_RTC), U4.46 (VDD3P3_CPU), U4.55 (VDDA), U4.56 (VDDA), U5.5 (VDDIO), U5.8 (VDD), U6.2 (VDD), U7.1 (VDDIO), U7.5 (SDO), U7.6 (CSB), U7.10 (VDD), U9.10 (~SRCLR), U9.16 (VCC), U10.8 (VCC)

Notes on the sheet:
These resistors near ESP

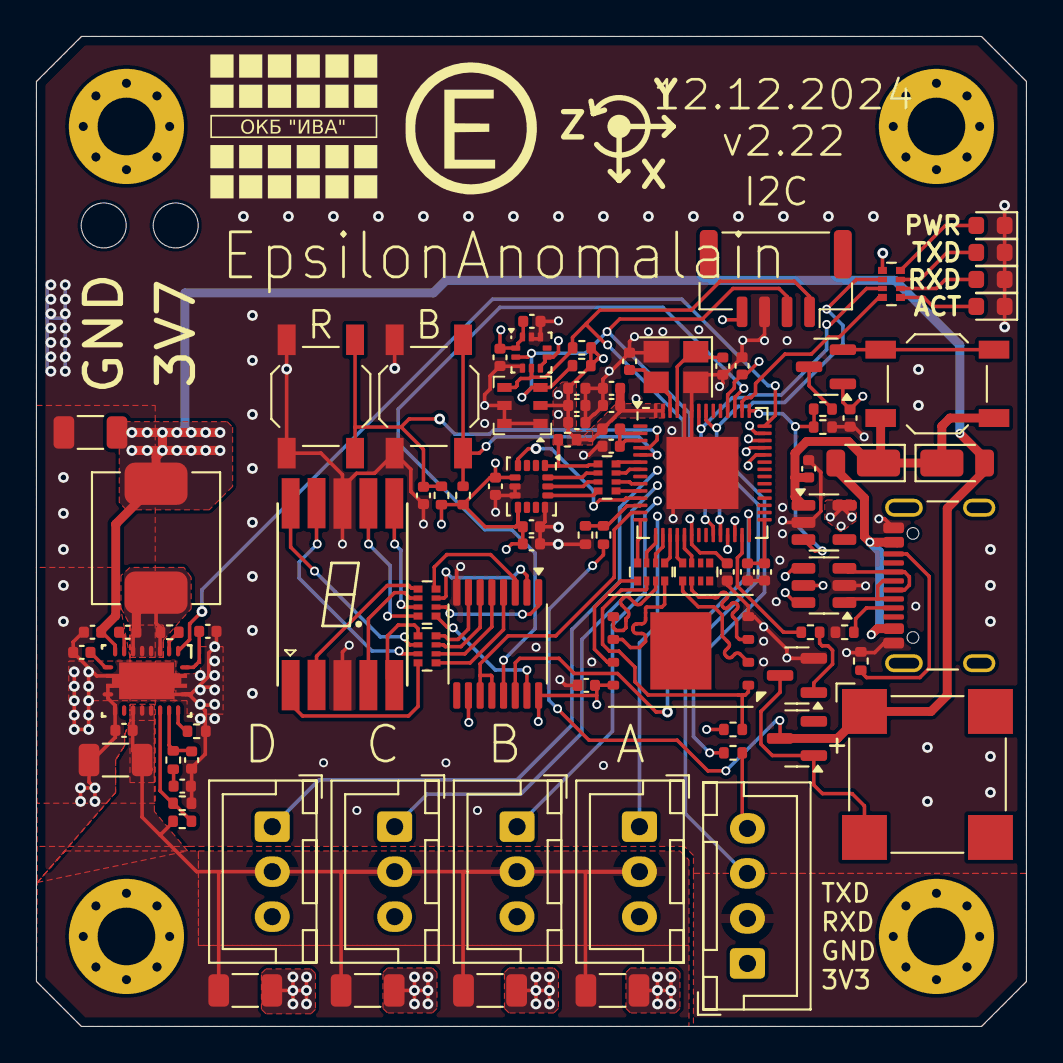
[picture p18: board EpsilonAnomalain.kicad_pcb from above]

Board: 4 copper layers, 55.0 x 55.0 mm, 97 parts (0 on the bottom side), 89 nets.

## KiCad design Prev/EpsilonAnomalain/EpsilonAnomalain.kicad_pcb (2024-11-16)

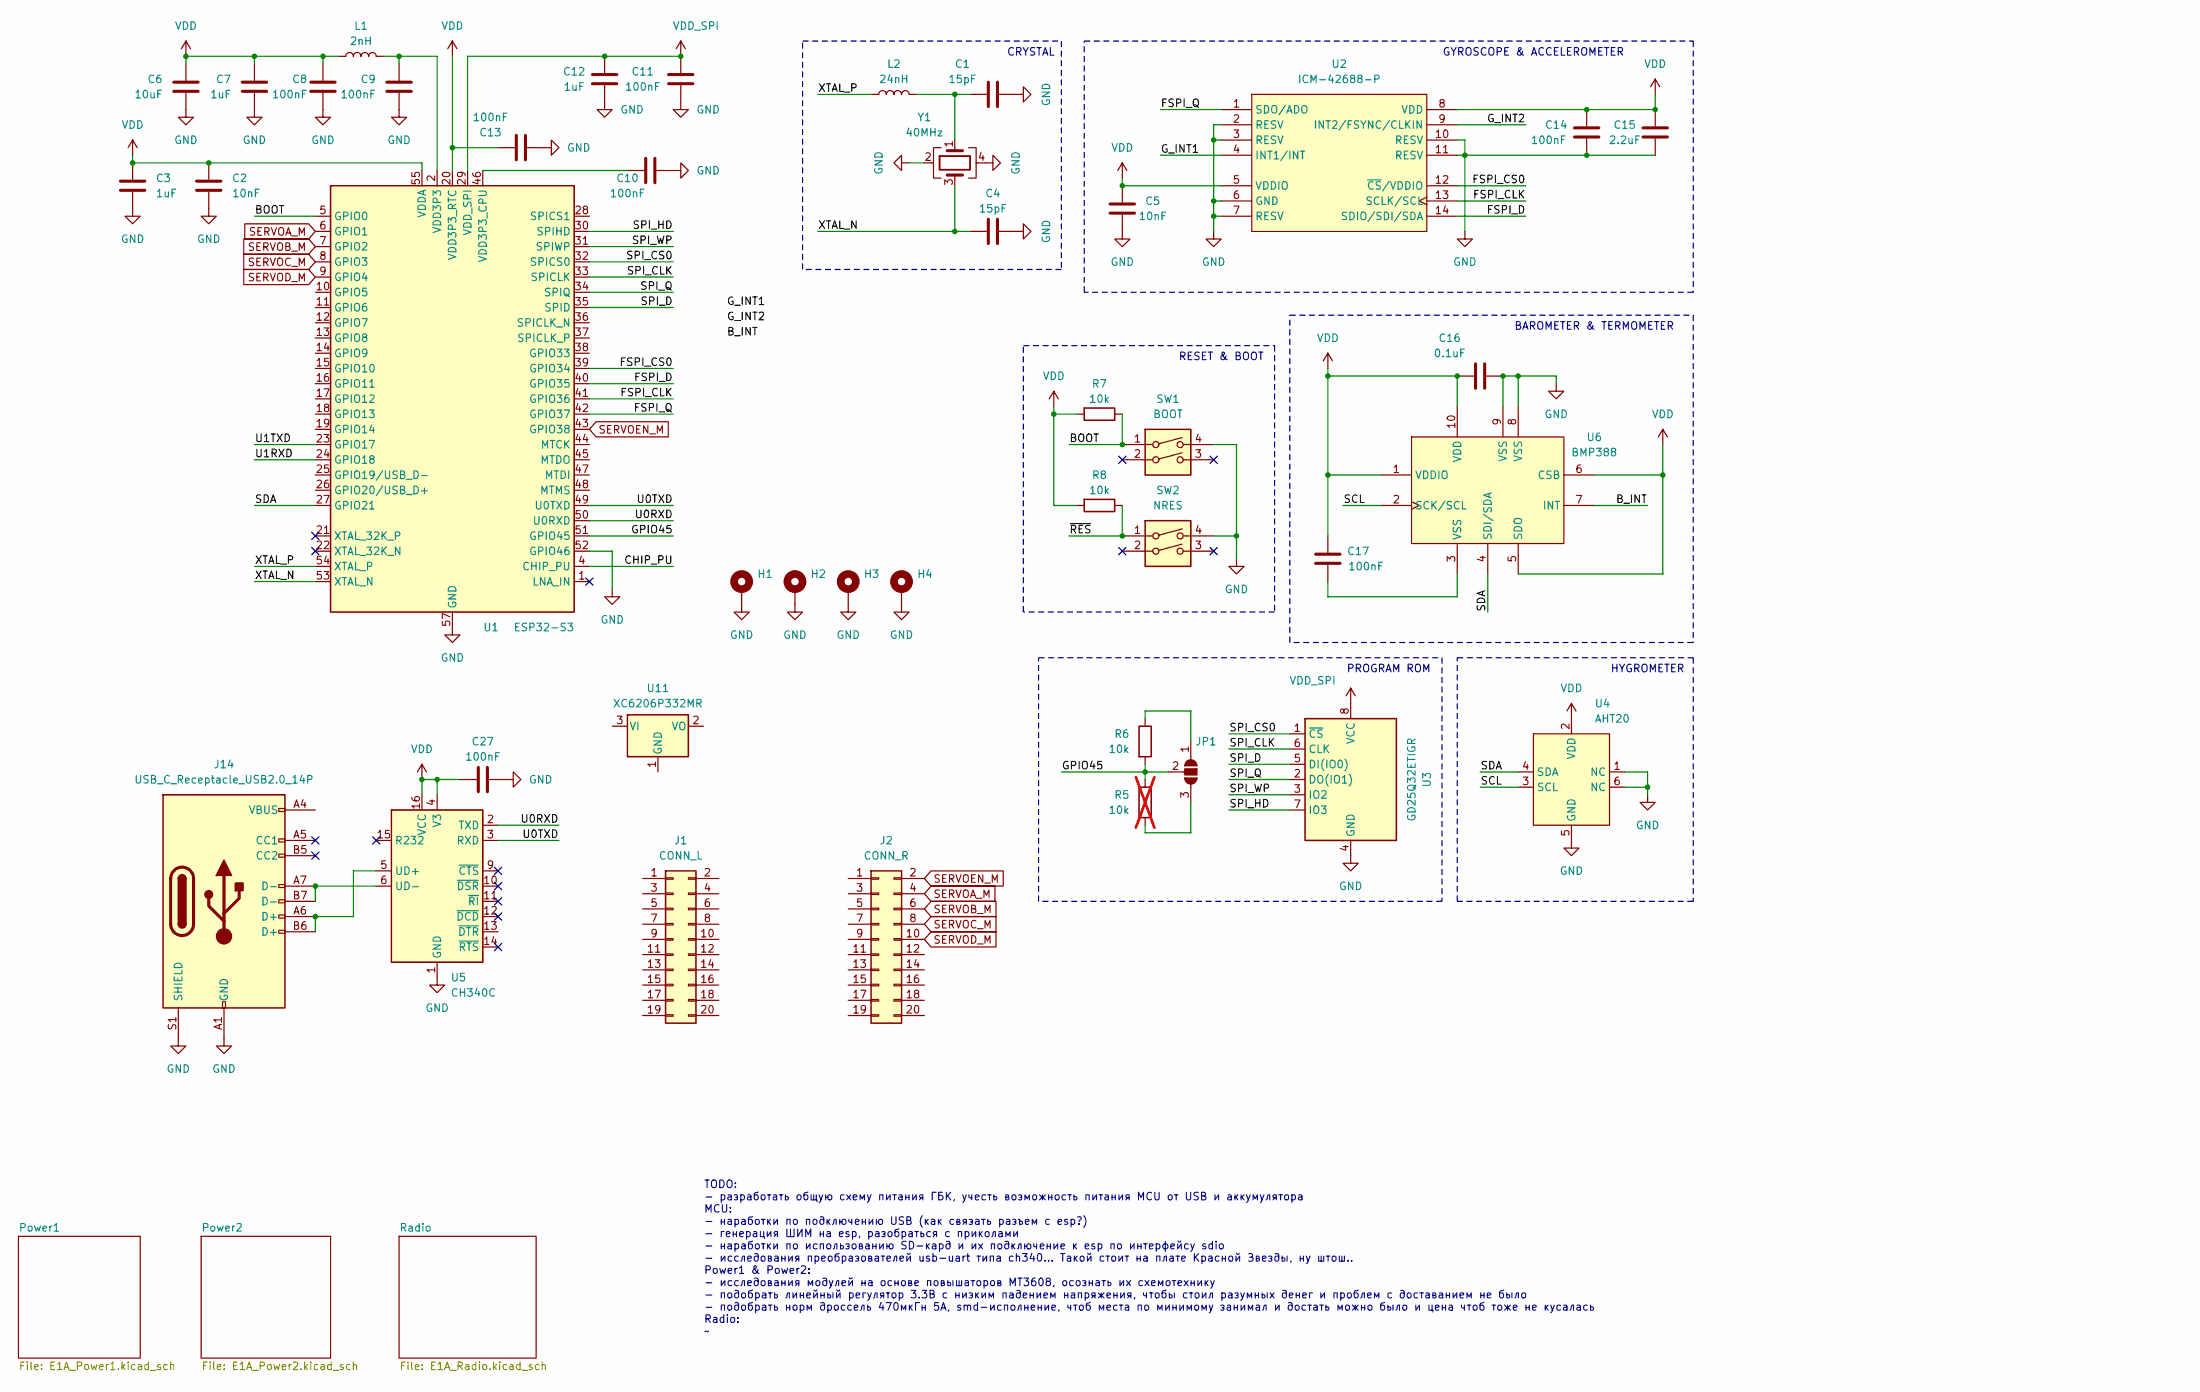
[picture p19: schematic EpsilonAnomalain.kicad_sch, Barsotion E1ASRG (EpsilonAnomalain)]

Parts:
C1, C4: 15pF; C_0402_1005Metric
C2, C5: 10nF; C_0402_1005Metric
C3, C7, C12: 1uF; C_0402_1005Metric
C6: 10uF; C_0402_1005Metric
C8, C9, C10, C11, C13, C14, C17, C27: 100nF; C_0402_1005Metric
C15: 2.2uF; C_0402_1005Metric
C16: 0.1uF; C_0402_1005Metric
H1, H2, H3, H4: MountingHole_Pad; MountingHole_3.2mm_M3_Pad_Via
J1: CONN_L; PinSocket_2x10_P2.54mm_Vertical_SMD
J2: CONN_R; PinSocket_2x10_P2.54mm_Vertical_SMD
J14: USB_C_Receptacle_USB2.0_14P; USB_C_Receptacle_GCT_USB4105-xx-A_16P_TopMnt_Horizontal
JP1: Flash_Supply; SolderJumper-3_P1.3mm_Open_RoundedPad1.0x1.5mm_NumberLabels
L1: 2nH; L_0402_1005Metric
L2: 24nH; L_0402_1005Metric
R5: 10k; R_0402_1005Metric; not fitted
R6, R7, R8: 10k; R_0402_1005Metric
SW1: BOOT; SW_Push_1P1T_XKB_TS-1187A
SW2: NRES; SW_Push_1P1T_XKB_TS-1187A
U1: ESP32-S3; QFN-56-1EP_7x7mm_P0.4mm_EP4x4mm
U2: ICM-42688-P; LGA-14_3x2.5mm_P0.5mm_LayoutBorder3x4y
U3: GD25Q32ETIGR; SOP-8_3.9x4.9mm_P1.27mm
U4: AHT20
U5: CH340C; SOIC-16_3.9x9.9mm_P1.27mm
U6: BMP388; ST_HLGA-10_2x2mm_P0.5mm_LayoutBorder3x2y
U11: XC6206P332MR; SOT-23-3
Y1: 40MHz; Crystal_SMD_3225-4Pin_3.2x2.5mm

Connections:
/BOOT: R7.1, SW1.1, U1.5 (GPIO0)
/B_INT: U6.7 (INT)
/CHIP_PU: U1.4 (CHIP_PU)
/FSPI_CLK: U1.41 (GPIO36), U2.13 (SCLK/SCL)
/FSPI_CS0: U1.39 (GPIO34), U2.12 (~CS/VDDIO)
/FSPI_D: U1.40 (GPIO35), U2.14 (SDIO/SDI/SDA)
/FSPI_Q: U1.42 (GPIO37), U2.1 (SDO/ADO)
/GPIO45: JP1.2 (C), R5.1, R6.2, U1.51 (GPIO45)
/G_INT1: U2.4 (INT1/INT)
/G_INT2: U2.9 (INT2/FSYNC/CLKIN)
/SCL: U4.3 (SCL), U6.2 (SCK/SCL)
/SDA: U1.27 (GPIO21), U4.4 (SDA), U6.4 (SDI/SDA)
/SPI_CLK: U1.33 (SPICLK), U3.6 (CLK)
/SPI_CS0: U1.32 (SPICS0), U3.1 (~CS)
/SPI_D: U1.35 (SPID), U3.5 (DI(IO0))
/SPI_HD: U1.30 (SPIHD), U3.7 (IO3)
/SPI_Q: U1.34 (SPIQ), U3.2 (DO(IO1))
/SPI_WP: U1.31 (SPIWP), U3.3 (IO2)
/U0RXD: U1.50 (U0RXD), U5.2 (TXD)
/U0TXD: U1.49 (U0TXD), U5.3 (RXD)
/U1RXD: U1.24 (GPIO18)
/U1TXD: U1.23 (GPIO17)
/XTAL_N: C4.2, U1.53 (XTAL_N), Y1.3
/XTAL_P: L2.1, U1.54 (XTAL_P)
/~RES: R8.1, SW2.1
GND: C1.1, C2.2, C3.2, C4.1, C5.2, C6.2, C7.2, C8.2, C9.2, C10.2, C11.2, C12.1, C13.2, C14.2, C15.2, C16.2, C27.1, H1.1, H2.1, H3.1, H4.1, J14.A1 (GND), J14.A12 (GND), J14.B1 (GND), J14.B12 (GND), J14.S1 (SHIELD), SW1.4, SW2.4, U1.52 (GPIO46), U1.57 (GND), U2.2 (RESV), U2.3 (RESV), U2.6 (GND), U2.7 (RESV), U2.10 (RESV), U2.11 (RESV), U3.4 (GND), U4.1 (NC), U4.5 (GND), U4.6 (NC), U5.1 (GND), U6.8 (VSS), U6.9 (VSS), Y1.2, Y1.4; also elsewhere on the board
unnamed: C1.2, L2.2, Y1.1
unnamed: C9.1, L1.2, U1.2 (VDD3P3), U1.3 (VDD3P3)
unnamed: C17.2, U6.3 (VSS)
unnamed: J14.A4 (VBUS), J14.A9 (VBUS), J14.B4 (VBUS), J14.B9 (VBUS)
unnamed: JP1.1 (A), R6.1
unnamed: JP1.3 (B), R5.2
unnamed: C10.1, U1.46 (VDD3P3_CPU)
unnamed: J14.A6 (D+), J14.B6 (D+), U5.5 (UD+)
unnamed: J14.A7 (D-), J14.B7 (D-), U5.6 (UD-)
SERVOA_M: J2.4, U1.6 (GPIO1)
SERVOB_M: J2.6, U1.7 (GPIO2)
SERVOC_M: J2.8, U1.8 (GPIO3)
SERVOD_M: J2.10, U1.9 (GPIO4)
SERVOEN_M: J2.2, U1.43 (GPIO38)
VDD_SPI: C11.1, C12.2, U1.29 (VDD_SPI), U3.8 (VCC)

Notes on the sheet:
GYROSCOPE & ACCELEROMETER
CRYSTAL
PROGRAM ROM
HYGROMETER
BAROMETER & TERMOMETER
RESET & BOOT
TODO: - разработать общую схему питания ГБК, учесть возможность питания MCU от USB и аккумулятора MCU: - наработки по подключению USB (как связать разъем с esp?) - генерация ШИМ на esp, разобраться с приколами - наработки по использованию SD-кард и их подключение к esp по интерфейсу sdio - исследов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

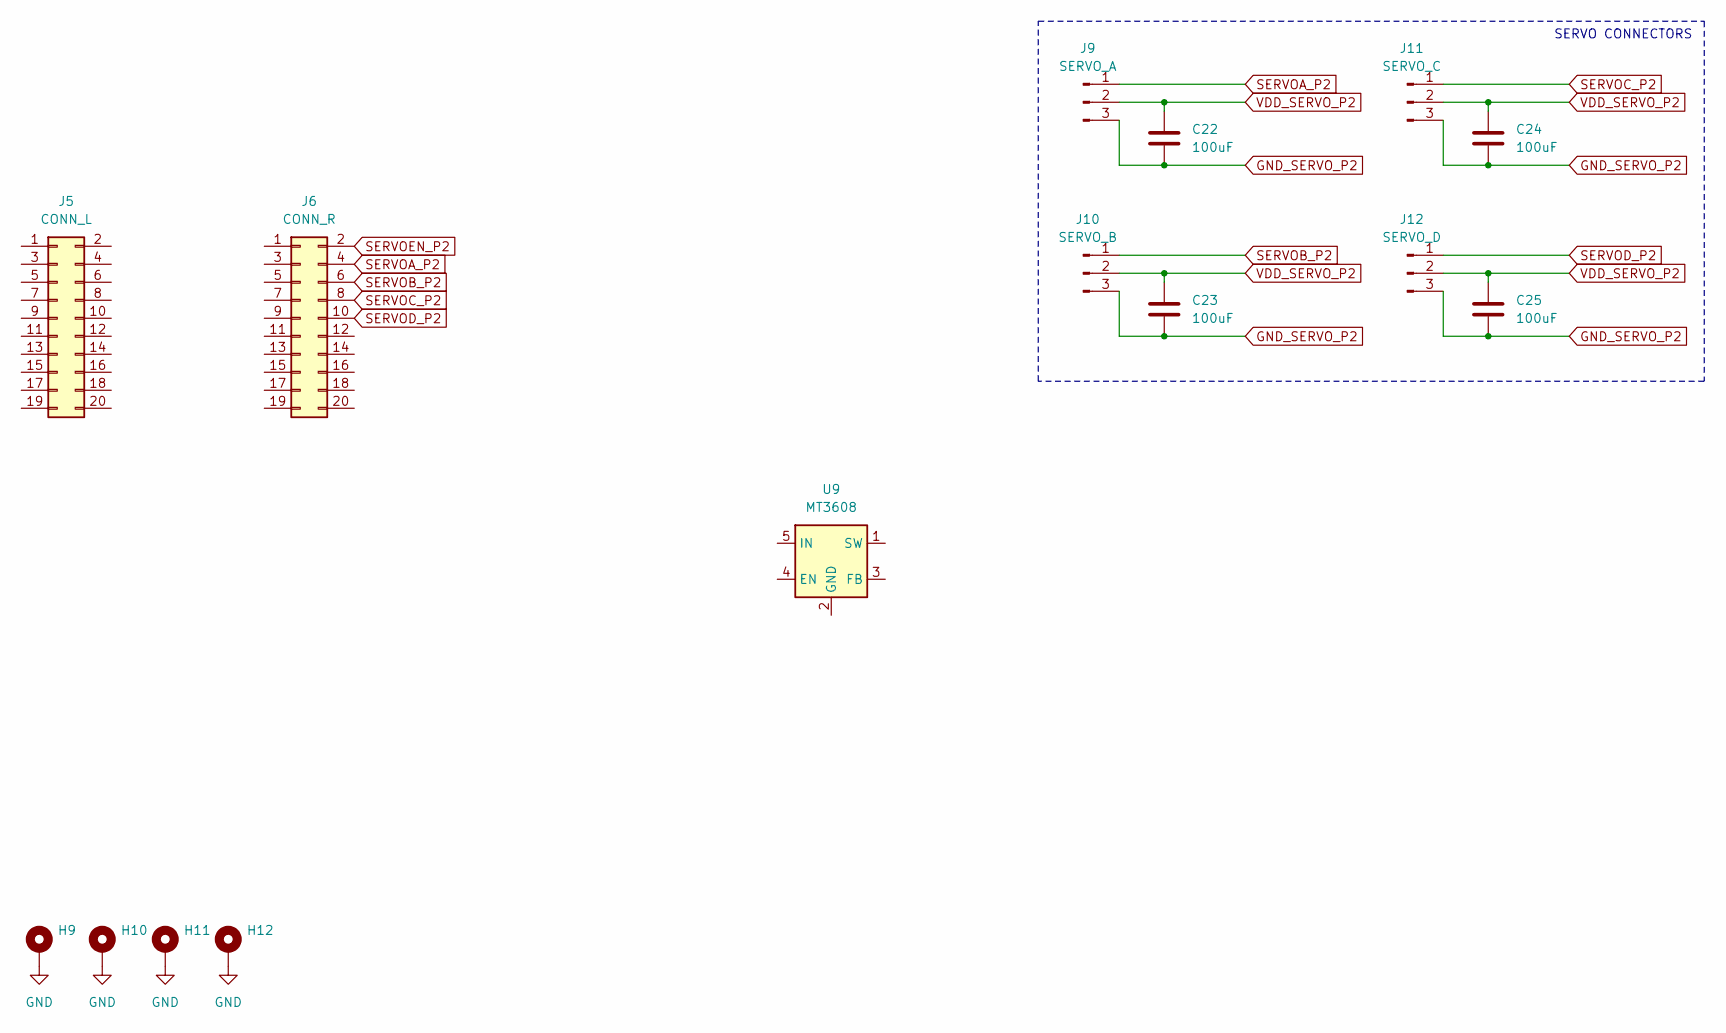
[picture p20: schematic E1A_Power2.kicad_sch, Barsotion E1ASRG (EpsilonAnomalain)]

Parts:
C22, C23, C24, C25: 100uF; C_1206_3216Metric
H9, H10, H11, H12: MountingHole_Pad; MountingHole_3.2mm_M3_Pad_Via
J5: CONN_L; PinSocket_2x10_P2.54mm_Vertical_SMD
J6: CONN_R; PinSocket_2x10_P2.54mm_Vertical_SMD
J9: SERVO_A; JST_EH_S3B-EH_1x03_P2.50mm_Horizontal
J10: SERVO_B; JST_EH_S3B-EH_1x03_P2.50mm_Horizontal
J11: SERVO_C; JST_EH_S3B-EH_1x03_P2.50mm_Horizontal
J12: SERVO_D; JST_EH_S3B-EH_1x03_P2.50mm_Horizontal
U9: MT3608; SOT-23-6

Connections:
GND: H9.1, H10.1, H11.1, H12.1; also elsewhere on the board
GND_SERVO_P2: C22.2, C23.2, C24.2, C25.2, J9.3, J10.3, J11.3, J12.3
SERVOA_P2: J6.4, J9.1
SERVOB_P2: J6.6, J10.1
SERVOC_P2: J6.8, J11.1
SERVOD_P2: J6.10, J12.1
SERVOEN_P2: J6.2
VDD_SERVO_P2: C22.1, C23.1, C24.1, C25.1, J9.2, J10.2, J11.2, J12.2

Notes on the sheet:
SERVO CONNECTORS

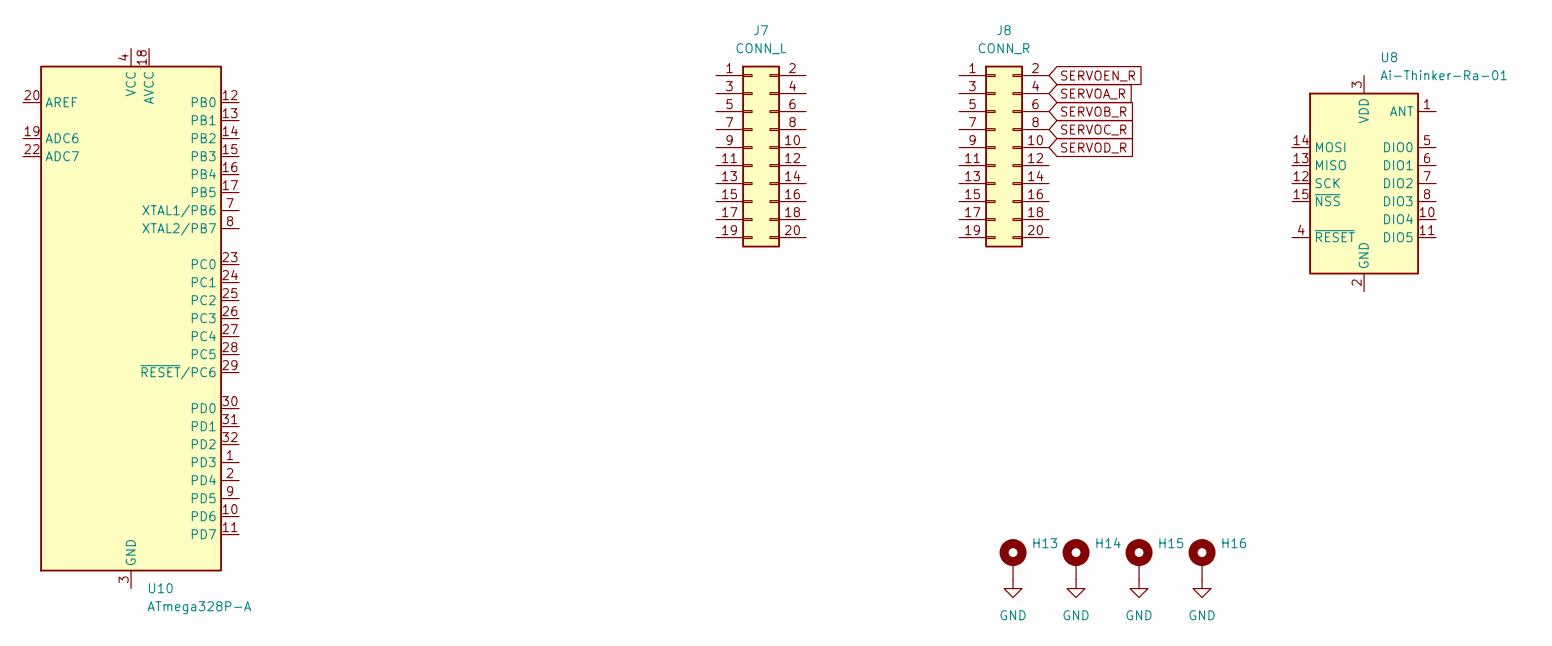
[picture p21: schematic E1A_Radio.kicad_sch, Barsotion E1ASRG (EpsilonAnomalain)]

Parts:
H13, H14, H15, H16: MountingHole_Pad; MountingHole_3.2mm_M3_Pad_Via
J7: CONN_L; PinSocket_2x10_P2.54mm_Vertical_SMD
J8: CONN_R; PinSocket_2x10_P2.54mm_Vertical_SMD
U8: Ai-Thinker-Ra-01; Ai-Thinker-Ra-01-LoRa
U10: ATmega328P-A; TQFP-32_7x7mm_P0.8mm

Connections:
GND: H13.1, H14.1, H15.1, H16.1; also elsewhere on the board
unnamed: U8.2 (GND), U8.9 (GND), U8.16 (GND)
unnamed: U10.3 (GND), U10.5 (GND), U10.21 (GND)
unnamed: U10.4 (VCC), U10.6 (VCC)
SERVOA_R: J8.4
SERVOB_R: J8.6
SERVOC_R: J8.8
SERVOD_R: J8.10
SERVOEN_R: J8.2

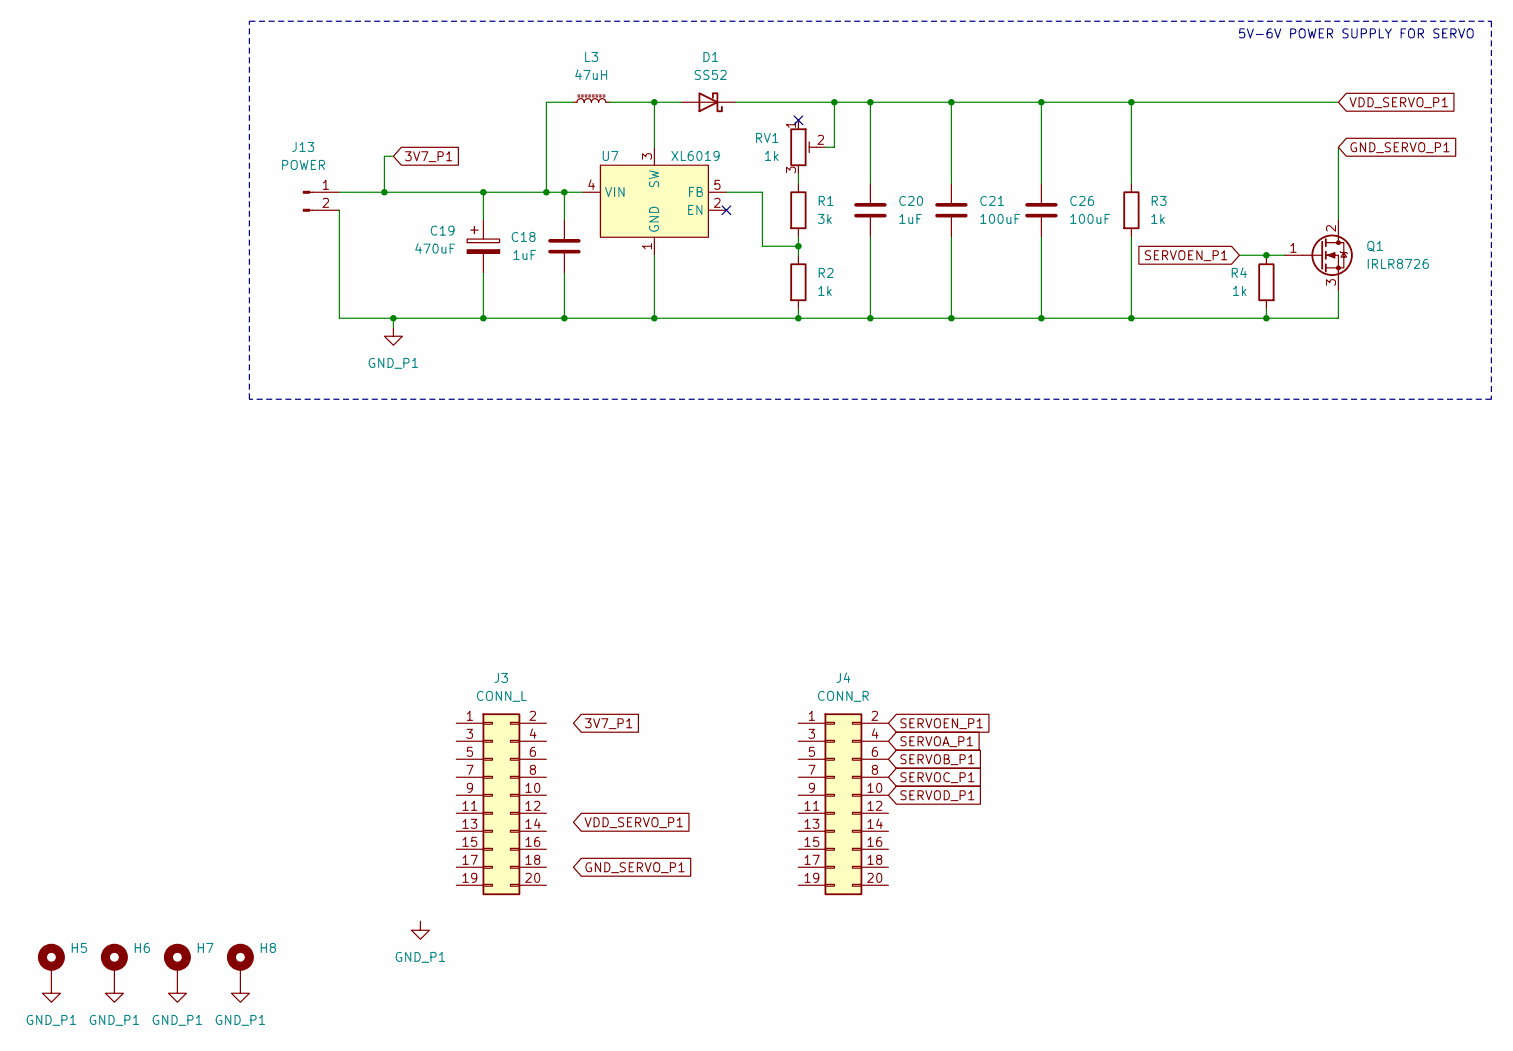
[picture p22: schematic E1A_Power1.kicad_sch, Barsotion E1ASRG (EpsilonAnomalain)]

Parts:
C18, C20: 1uF; C_0402_1005Metric
C19: 470uF
C21, C26: 100uF; C_1206_3216Metric
D1: SS52; D_SMA
H5, H6, H7, H8: MountingHole_Pad; MountingHole_3.2mm_M3_Pad_Via
J3: CONN_L; PinSocket_2x10_P2.54mm_Vertical_SMD
J4: CONN_R; PinSocket_2x10_P2.54mm_Vertical_SMD
J13: POWER
L3: 47uH; L_Sunlord_MWSA1206S-470
Q1: IRLR8726; TO-252-2
R1: 3k; R_0402_1005Metric
R2, R3, R4: 1k; R_0402_1005Metric
RV1: 1k; Potentiometer_Bourns_TC33X_Vertical
U7: XL6019; TO-263-5_TabPin3

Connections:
3V7_P1: C18.1, C19.1, J13.1, L3.1, U7.4 (VIN)
GND_P1: C18.2, C19.2, C20.2, C21.2, C26.2, H5.1, H6.1, H7.1, H8.1, J13.2, Q1.3 (S), R2.2, R3.2, R4.2, U7.1 (GND)
GND_SERVO_P1: Q1.2 (D)
unnamed: D1.2 (A), L3.2, U7.3 (SW)
unnamed: R1.1, RV1.3
unnamed: R1.2, R2.1, U7.5 (FB)
SERVOA_P1: J4.4
SERVOB_P1: J4.6
SERVOC_P1: J4.8
SERVOD_P1: J4.10
SERVOEN_P1: J4.2, Q1.1 (G), R4.1
VDD_SERVO_P1: C20.1, C21.1, C26.1, D1.1 (K), R3.1, RV1.2

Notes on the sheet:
5V-6V POWER SUPPLY FOR SERVO

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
Board: 2 copper layers, 83 parts (0 on the bottom side), 53 nets, no tracks yet.

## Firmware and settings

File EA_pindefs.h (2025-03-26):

/* Pin defines for Barsotion-EA_v2 board */

#ifndef EA_PINDEFS_H
#define EA_PINDEFS_H

#ifdef __cplusplus
extern "C" {
#endif

/* VSPI & FSPI */
#define VSPI_Q_PINNUM			(gpio_num_t)1
#define VSPI_D_PINNUM			(gpio_num_t)2
#define VSPI_CLK_PINNUM			(gpio_num_t)4
#define VSPI_CS_PINNUM			(gpio_num_t)5
#define FSPI_Q_PINNUM			(gpio_num_t)13
#define FSPI_D_PINNUM			(gpio_num_t)11
#define FSPI_CLK_PINNUM			(gpio_num_t)12
#define FSPI_CS_PINNUM			(gpio_num_t)10
#define FSPI_HD_PINNUM			(gpio_num_t)9
#define FSPI_WP_PINNUM			(gpio_num_t)14
/* I2C bus */
#define SDA_PINNUM				(gpio_num_t)17
#define SCL_PINNUM				(gpio_num_t)18
/* UART0 bus */
#define TXD0_PINNUM				(gpio_num_t)43
#define RXD0_PINNUM				(gpio_num_t)44
/* Servo */
#define SERVOEN_PINNUM			(gpio_num_t)37
#define SERVOA_PINNUM			(gpio_num_t)33
#define SERVOB_PINNUM			(gpio_num_t)34
#define SERVOC_PINNUM			(gpio_num_t)35
#define SERVOD_PINNUM			(gpio_num_t)36
/* ADC */
#define VPROBE_ADC_CHANNEL		ADC1_CH6
#define VPROBE_PINNUM			(gpio_num_t)7
/* Other pins */
#define ACTION_PINNUM			(gpio_num_t)39
#define BUZ_PINNUM				(gpio_num_t)21
#define LD_CLK_PINNUM			(gpio_num_t)8
#define LD_D_PINNUM				(gpio_num_t)26 //???
#define OFF_PINNUM				(gpio_num_t)38


/* IMU */
#define IMU_SPI_HOST			SPI3_HOST
#define IMU_MISO_PINNUM			VSPI_Q_PINNUM
#define IMU_MOSI_PINNUM			VSPI_D_PINNUM
#define IMU_SCK_PINNUM			VSPI_CLK_PINNUM
#define IMU_CS_PINNUM			VSPI_CS_PINNUM
#define IMU_INT_PINNUM			(gpio_num_t)6
/* SPI NAND Flash */
#define FLASH_SPI_HOST			SPI2_HOST
#define FLASH_D0_PINNUM			FSPI_D_PINNUM
#define FLASH_D1_PINNUM			FSPI_Q_PINNUM
#define FLASH_D2_PINNUM			FSPI_WP_PINNUM
#define FLASH_D3_PINNUM			FSPI_HD_PINNUM
#define FLASH_SCK_PINNUM		FSPI_SCK_PINNUM
#define FLASH_CS_PINNUM			FSPI_CS_PINNUM

#ifdef __cplusplus
}
#endif

#endif /* EA_PINDEFS_H */
